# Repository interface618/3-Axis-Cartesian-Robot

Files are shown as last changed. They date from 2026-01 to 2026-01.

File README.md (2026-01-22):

<p align='center'>


<div align="center">
<h2>[2024] 3축 직교 좌표 로봇을 활용한 자동 분리수거 장치 ♻️</h2>
AI 기반 스마트 분리수거 시스템은 웹캠과 딥러닝 모델로 폐기물을 인식한 후 3축 직교좌표 로봇이 자동으로 분류까지 수행하는 시스템입니다.<br> 분류 이후에는 초음파 세척으로 이물질을 제거해 재활용품 품질까지 함께 관리합니다.<br>
</div>

## 목차
  - [개요](#개요) 
  - [작품 설명](#작품-설명)
  - [작품 작동 방식](#작품-작동-방식)
  - [역할 및 내용](#역할-및-내용)
  - [트러블 슈팅](#트러블-슈팅)
  - [코멘트](#코멘트)
## 개요
- 프로젝트 이름: ♻️ 3축 직교 좌표 로봇을 활용한 자동 분리수거 장치 ♻️
- 프로젝트 기간: 2024.07-2024.11
- 개발 엔진 및 언어: C & Python
- 멤버: Interface (이윤승 ,문영민 ,박승규 ,최성원)

## 작품 설명

현대 사회에서 재활용률 저하, 잘못된 분리수거, 이물질·라벨로 인한 재활용 품질 저하 문제를 해결하기 위해, AI 인식 + 자동 분류 + 초음파 세척 + IoT 모니터링을 하나의 운영 흐름으로 통합한 스마트 분리수거 시스템입니다.<br>
사용자가 쓰레기를 투입하면, 시스템이 객체를 인식하고 분류한 뒤 세척까지 수행하여 재활용 가능 상태로 만드는 것을 목표로 합니다.

## 작품 작동 방식

https://github.com/user-attachments/assets/98984104-4c1d-4c73-a88f-227e68fc7fe7

https://github.com/user-attachments/assets/f7063f24-820b-4ae6-a235-6e6485c27786

<h2>역할 및 내용</h2>

<table align="center">
  <thead>
    <tr>
      <th align="center">이름</th>
      <th align="center">담당 역할</th>
      <th align="center">내용</th>
    </tr>
  </thead>
  <tbody>
    <tr>
      <td nowrap align="center">이윤승</td>
      <td align="center">
        프로젝트 총괄 및<br>오수 처리 시스템 설계<br>
        초음파 세척 기능 구현, 컨베이어 벨트 제어 설계 및 3D 모델링
      </td>
      <td align="center">
        전체 요구사항/일정 관리, 모듈 간 인터페이스 정의, 오수 처리 프로세스(흐름/안전/운영 시나리오) 설계 및 통합 검증 주도<br>
        초음파 세척 모듈 구현 및 동작 조건 튜닝, 컨베이어 구동/제어 로직 설계, 기구 부품 3D 모델링 및 제작 지원
      </td>
    </tr>
    <tr>
      <td nowrap align="center">문영민</td>
      <td align="center">전원공급장치(파워서플라이)<br>설계 및 제작</td>
      <td align="center">시스템 요구 전력 분석, 전원부 구성/부품 선정, 안정적인 전원 공급을 위한 설계 반영 및 제작, 동작 테스트/검증 수행</td>
    </tr>
    <tr>
      <td nowrap align="center">박승규</td>
      <td align="center">직교좌표 로봇 제어 설계</td>
      <td align="center">3축(직교좌표) 구동 로직 설계, 홈 포지션/원점 복귀 등 안정 운용 시나리오 구성, 반복 동작 정밀도 개선을 위한 제어 파라미터 조정</td>
    </tr>
    <tr>
      <td nowrap align="center">최성원</td>
      <td align="center">영상처리 및<br>사물인식 프로그램 설계</td>
      <td align="center">카메라 기반 인식 파이프라인 설계, 인식 결과(좌표/상태) 산출 및 제어부 전달 구조 구성, 현장 디버깅을 통한 인식/전송 안정화</td>
    </tr>
  </tbody>
</table>

## 트러블 슈팅

- **3D 프린팅 출력물 규격 불일치(조립 공차 문제)**
  - 문제: 3D 모델링한 부품이 조립 시 규격이 맞지 않거나, 출력물이 예상 치수/형상과 다르게 출력되는 문제가 발생했습니다.
  - 원인: 모델 스케일/단위 설정 오류, 프린터 캘리브레이션 미흡, 슬라이서 파라미터(수축·유량·온도 등) 영향으로 치수 편차가 발생했습니다.
  - 해결: 모델 치수 재검증 후 스케일을 조정하고, 테스트 출력으로 프린터 설정(온도/속도/수축 보정)을 최적화했으며, FUSION 360에서 제공하는 조립 기능을 이용하여 시행착오를 줄였습니다.
  - 결과: 조립 공차를 만족하는 출력물을 확보하여 기구 조립을 정상적으로 진행했습니다.

- **카메라 인식 값 ↔ 직교좌표 로봇 전송(통신) 불안정**
  - 문제: 카메라에서 인식한 좌표/오프셋 값을 직교좌표 로봇 제어부로 전달하는 과정에서 값 누락/오류 등으로 정상적인 송신이 어려웠습니다.
  - 원인: 데이터 포맷 불일치, 통신 속도/버퍼 처리, 예외 상황 처리 미흡 등으로 전송 안정성이 떨어졌습니다.
  - 해결: 전송 포맷을 명확히 정의하고, 코드를 단계적으로 수정하면서 로그 기반 디버깅을 수행해 예외 처리와 버퍼 관리를 보완했습니다.
  - 결과: 인식 결과가 안정적으로 송신되며 로봇 제어에 정상 반영되었습니다.

- **파워서플라이 제작 중 손상(과전류/단락 위험)**
  - 문제: 파워서플라이 제작을 위해 제품을 분해·조립하는 과정에서 전원부가 손상되는 위기가 있었습니다.
  - 원인: 배선/결선 실수, 단락 가능성, 보호 회로 부족 등으로 전원부에 과부하가 걸릴 위험이 있었습니다.
  - 해결: 예비 전원부를 준비해 리스크를 낮추고, 결선을 하나씩 재점검하며 보호 요소(배선 정리, 절연, 연결 순서 점검 등)를 강화했습니다.
  - 결과: 시스템 요구에 맞는 안정적인 전원 공급용 파워서플라이를 구성했습니다.

- **타이밍 벨트 장력 저하로 인한 구동 불량**
  - 문제: 3축 직교좌표 로봇 구동 중 타이밍 벨트가 느슨해져 슬립이 발생하고 동작이 불안정해졌습니다.
  - 원인: 장력 부족 및 반복 구동에 따른 장력 변화로 전달 오차가 발생했습니다.
  - 해결: 벨트 장력을 재조정해 타이트하게 맞추고, 구동부 체결 상태를 재점검했습니다.
  - 결과: 축 이동이 안정화되고 반복 동작 신뢰도가 개선되었습니다.

- **장시간 구동 시 스텝 누적 오차(부동소수점 누적)**
  - 문제: 3축 직교좌표 로봇을 장시간 구동하면, 이동 스텝 값을 float(부동소수점) 기반으로 누적 계산하는 과정에서 미세 오차가 계속 쌓여 목표 위치 대비 편차가 발생했습니다.
  - 원인: 부동소수점 연산의 근사 오차가 반복적으로 누적되면서, 스텝/좌표 환산 값이 장기적으로 드리프트하는 특성이 있었습니다.
  - 해결: 누적 오차를 주기적으로 초기화하기 위해 **5분마다 홈 포지션(Home Position)으로 자동 이동**하여 기준점을 재정렬하고, 내부 좌표/스텝 누적 값을 **0으로 리셋**하는 방식으로 운용 로직을 추가했습니다.
  - 결과: 장기 구동에서도 좌표 드리프트가 억제되어 반복 작업 정밀도와 신뢰성이 개선되었습니다.

## 코멘트

- 초기 설계 단계에서 타이밍 벨트 장력 유지와 스텝 누적 오차(부동소수점 드리프트)를 충분히 고려하지 못해, 장시간 구동 후에야 슬립과 위치 편차 문제가 드러난 점이 아쉬웠습니다. 다음에는 장력 텐셔너/고정 구조를 더 견고하게 설계하고, 부동소수점 누적 오차를 줄이는 보정 로직과 주기적 홈 포지션 리셋 주기를 더 체계적으로 검증해 장기 운용 신뢰도를 근본적으로 높이고 싶습니다.

- H/W를 설계할 때 FUSION 360에 있는 시뮬레이션 툴을 사용하지 않고 실제로 출력하면서 피드백 받는 방식이 재료비 사용을 비효율적이게 운용한것 같아서 아쉬웠던 것 같다 다음에 H/W 설계할때는 시뮬레이션 툴을 사용하여 재료비 사용을 효율적으로 운용해보겠다.

- H/W 설계와 제작을 집중한 나머지 STM32의 코드 스타일을 아두이노 스타일 코딩을 해서 S/W 퀄리티가 좋지 못했던 것 같다 다음에는 역할 분배할때 H/W와 S/W 비율을 잘 조정해야할 것 같다.

- 데이터셋의 제한성이 가장 큰 문제였다. 학습에 사용한 데이터가 제한된 환경에서 수집된 이미지 중심으로 구성되어 있어, 다양한 조명 조건, 배경, 쓰레기 형태 변화에 대한 일반화 성능이 충분하지 않았다. 특히 라벨이 훼손된 플라스틱, 찌그러진 캔, 이물질이 묻은 폐기물 등 실제 분리수거 환경에서 자주 발생하는 변형된 객체에 대해 오검출 또는 미검출이 발생하는 사례가 확인되었다. 이를 통해 , 정부에서 지원해주는 AI 데이터셋을 다음에는 이용해서 더 좋은 결과를 만들고 싶다.

- 환경 요인에 따른 인식 성능 저하가 나타났다. 컨베이어 벨트 상에서 이동하는 객체는 모션 블러가 발생하고, 조명 변화 및 그림자에 따라 동일한 객체라도 인식 확률이 크게 변동하였다. 이로 인해 직교좌표 로봇의 픽앤플레이스 동작이 지연되거나 잘못된 분류 결과가 발생하는 문제가 있었다. 작업이 다 끝난 후 , OpenCV의 흑백 전환을 이용해서 물체의 형태로 구분을 했으면 더 좋은 결과가 나왔을거 같아 아쉬운 경험이였다.

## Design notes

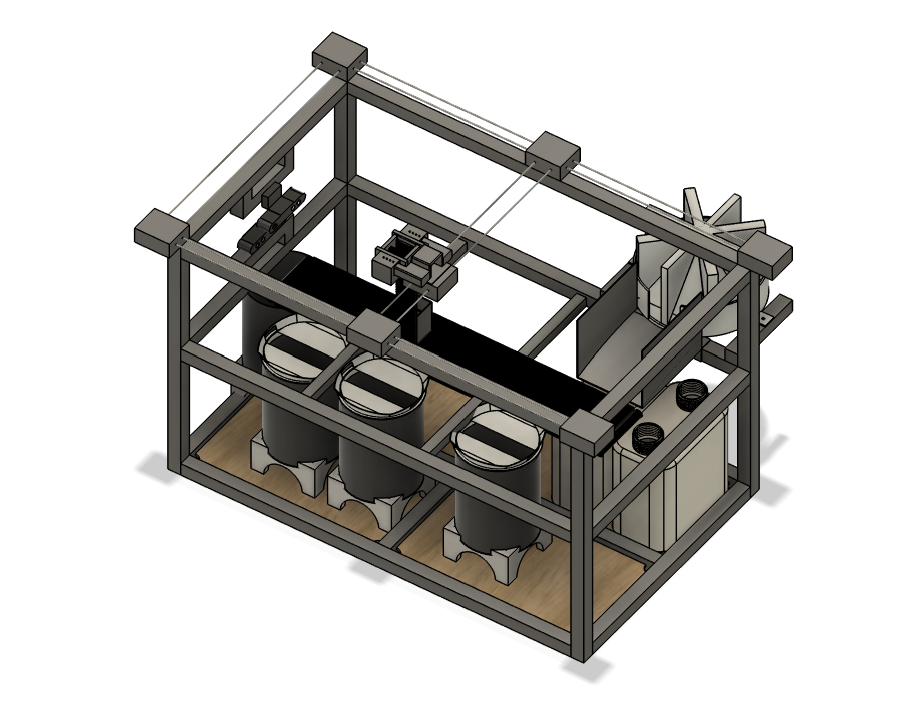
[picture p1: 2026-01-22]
3D/Total.Modeling.png

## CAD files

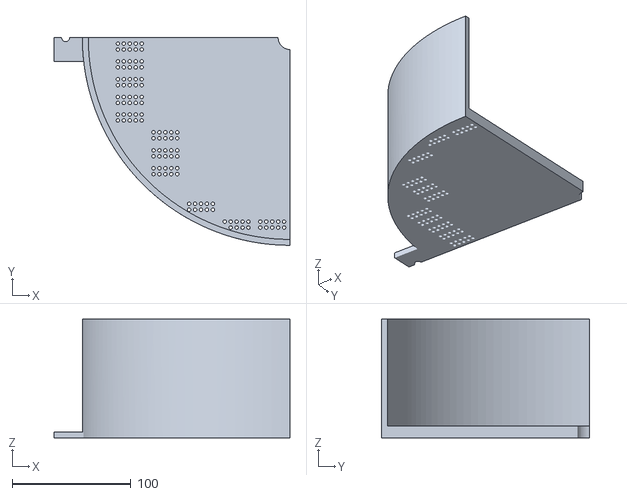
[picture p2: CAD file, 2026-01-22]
3D/분류기(외피) PART 1.stl
198.9 x 175.0 x 100.0

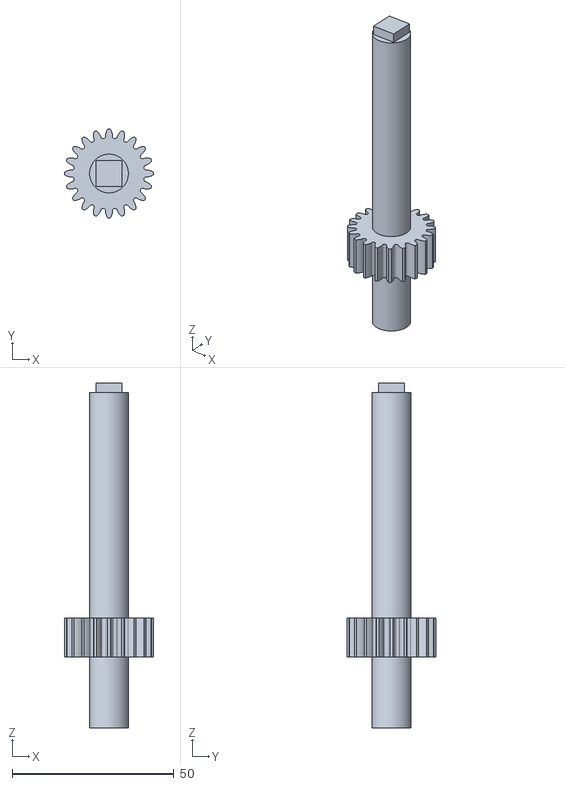
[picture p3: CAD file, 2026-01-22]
3D/분쇄기(L) 파트+Gear.stl
27.5 x 27.5 x 106.8

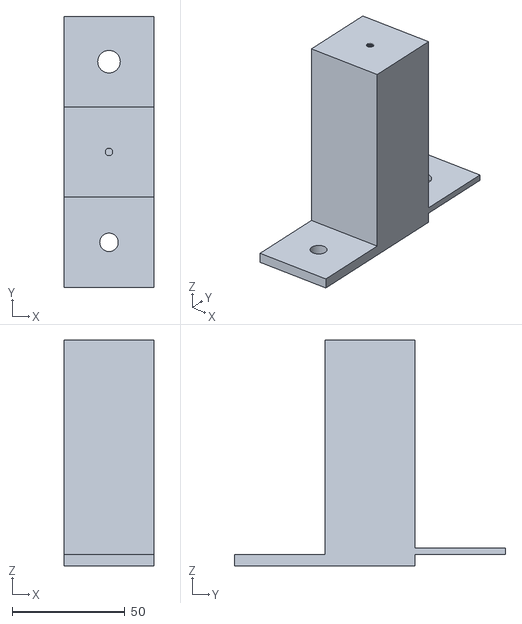
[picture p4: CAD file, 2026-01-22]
3D/쓰레기 분류기 받침대 PART 3.stl
40.0 x 120.0 x 100.0

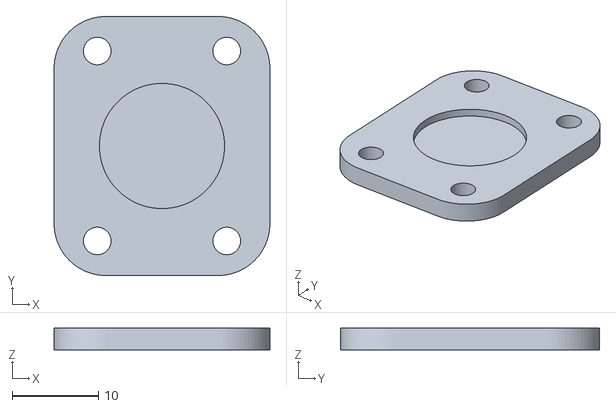
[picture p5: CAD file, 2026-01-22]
3D/압력센서 브라켓.stl
25.0 x 30.0 x 2.50

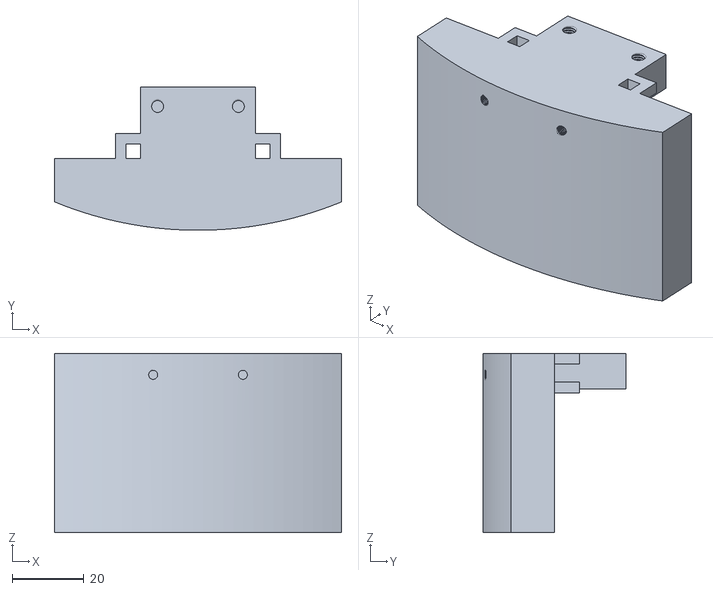
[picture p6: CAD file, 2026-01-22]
3D/초음파 수위센서 브라켓.stl
80.0 x 40.0 x 50.0

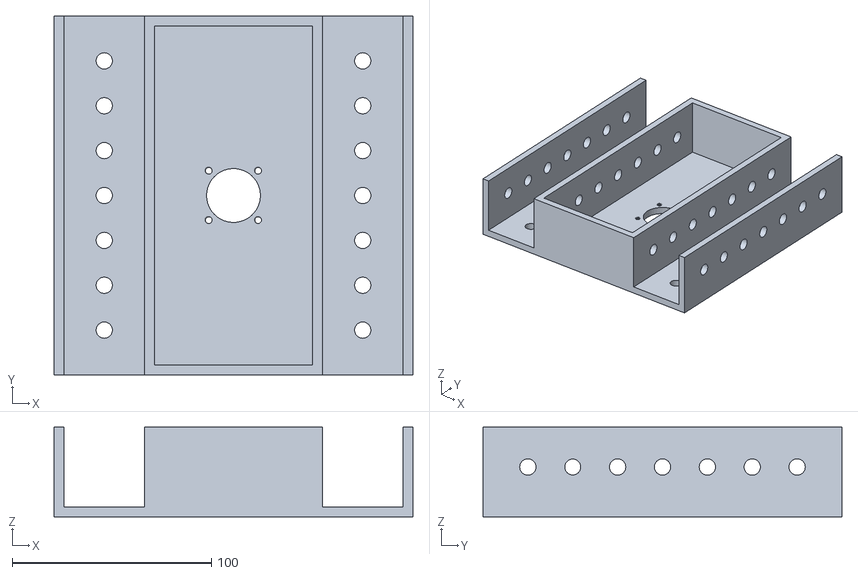
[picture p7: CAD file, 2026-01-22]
3D/K42-0084.stl
180.0 x 180.0 x 45.0

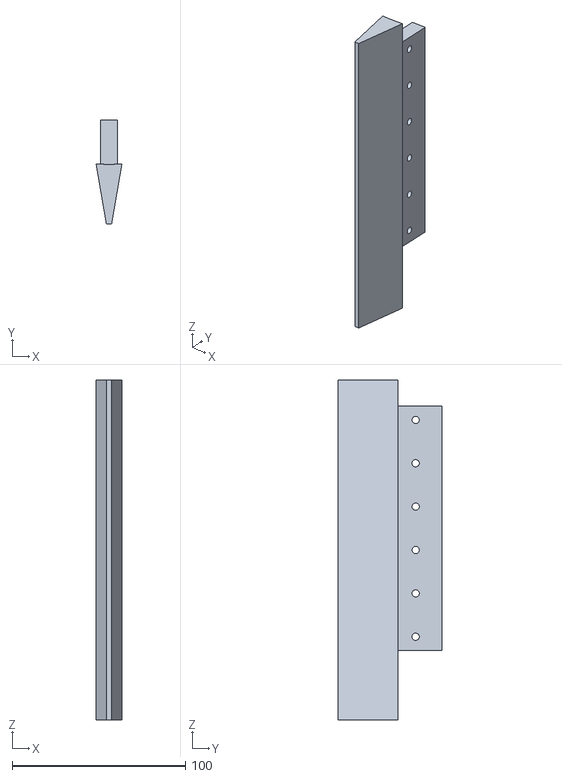
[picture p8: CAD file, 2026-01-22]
3D/쓰레기 분류기 날개(신).stl
14.9 x 60.2 x 196.0

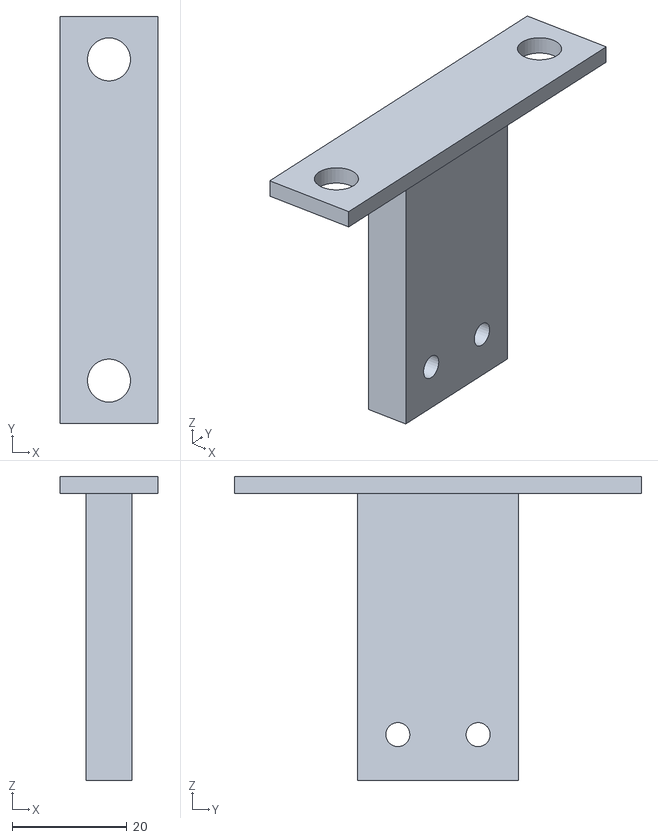
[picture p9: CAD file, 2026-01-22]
3D/베어링 브라켓(커튼 월).stl
17.0 x 71.0 x 53.0

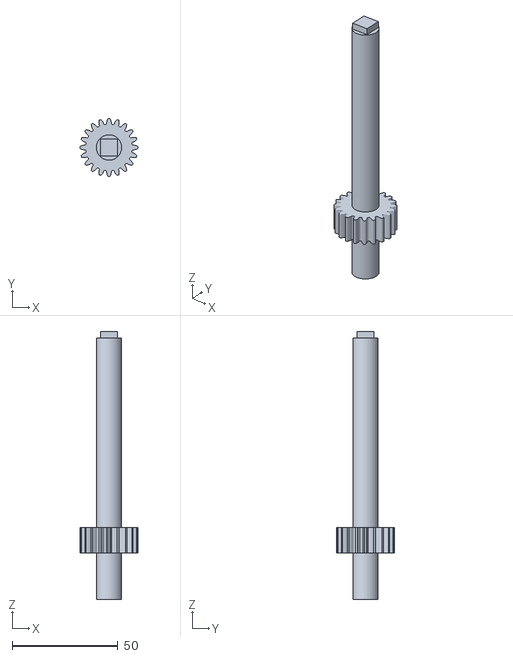
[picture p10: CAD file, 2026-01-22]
3D/분쇄기(R) 파트+Gear.stl
27.5 x 27.5 x 126.8

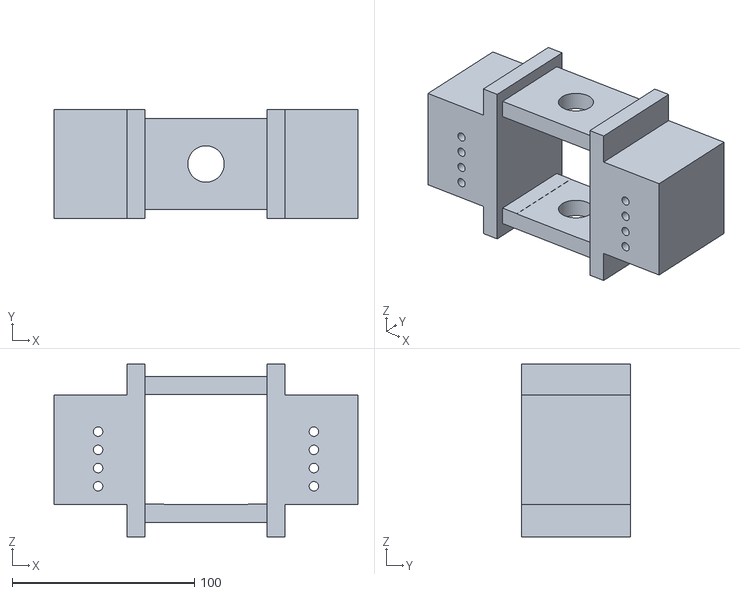
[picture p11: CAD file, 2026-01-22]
3D/M54 mk3 v8.stl
166.9 x 60.0 x 95.0

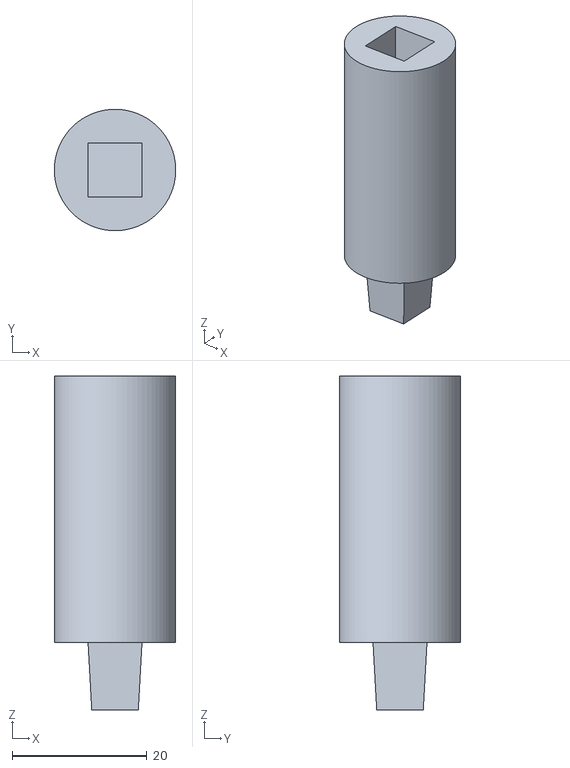
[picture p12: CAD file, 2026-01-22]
3D/분쇄기 파트 2.stl
18.0 x 18.0 x 49.5

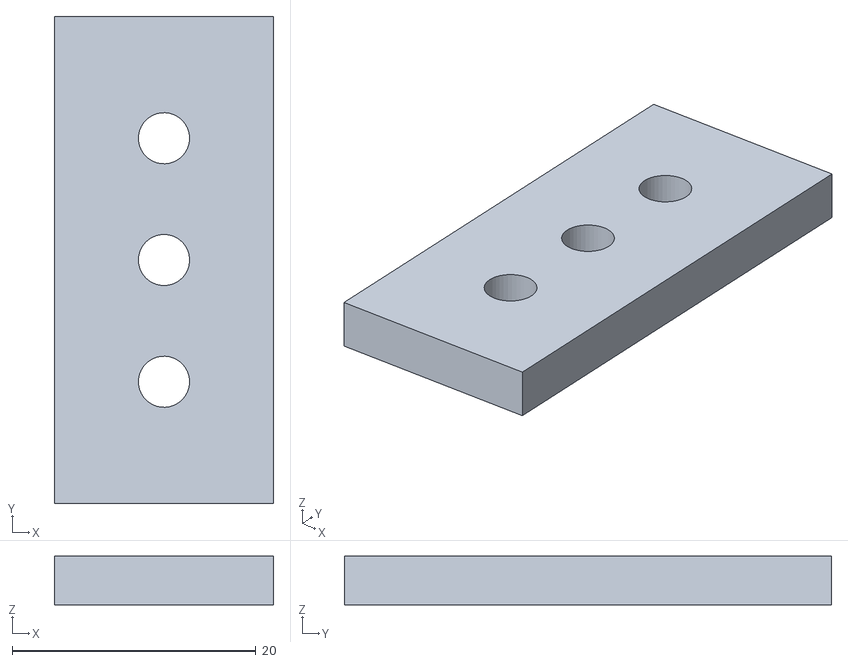
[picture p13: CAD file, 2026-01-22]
3D/부착물.stl
18.0 x 40.0 x 4.00

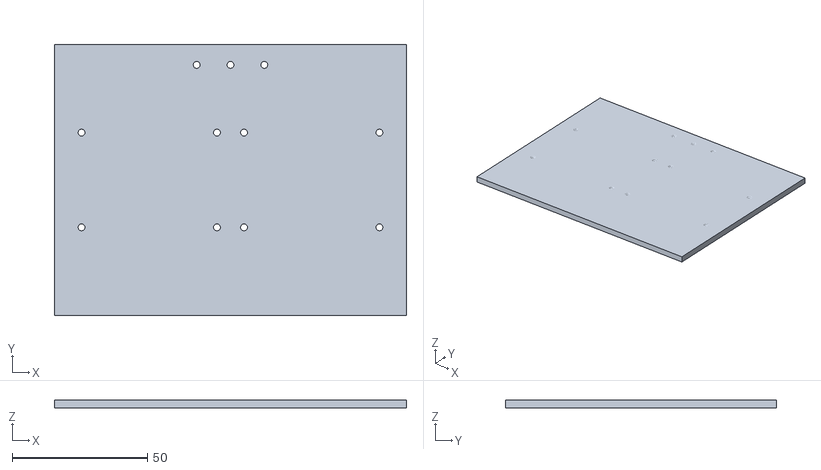
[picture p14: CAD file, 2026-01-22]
3D/워터펌프 브라켓.stl
130.0 x 100.0 x 3.00

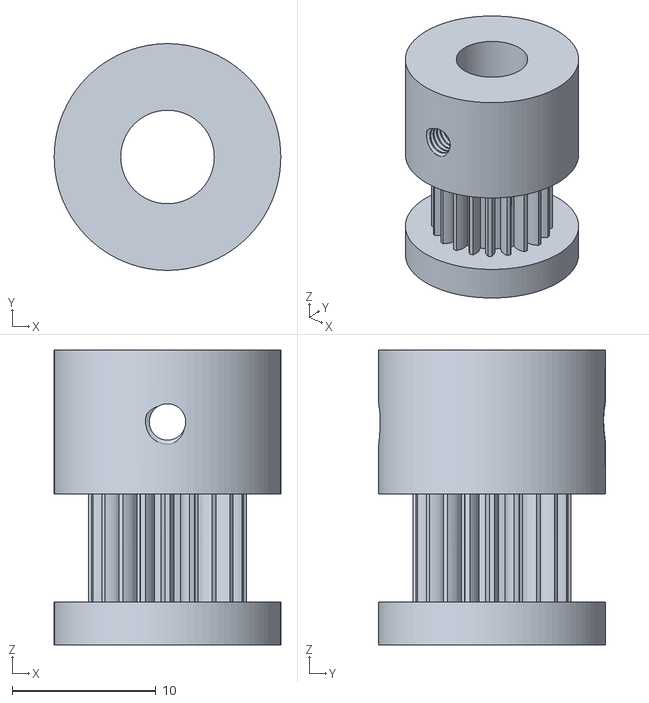
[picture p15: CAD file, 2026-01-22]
3D/GT2 풀리.stl
15.8 x 15.8 x 20.5

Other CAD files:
3D/케이블 체인 브라켓.stl
3D/쓰레기받이 상단 PART 1.stl
3D/압력센서 브라켓3 (RE) 파트 2.stl
3D/베어링 브라켓.stl
3D/Astra Pro Plus 브라켓.stl
3D/Astra Pro Plus.stl
3D/HC_SR04(BACK).stl
3D/HC_SR04(FRONT).stl
3D/M54 부속품 mk3 v3 PART 1.stl
3D/M54 부속품 mk3 v3.stl
3D/NEWTC 스텝모터 브라켓 파트 1(수정).stl
3D/c920.stl
3D/기어.stl
3D/기어봉.stl
3D/레일 version 1.stl
3D/레일 부속품 1.stl
3D/레일 부속품 3.stl
3D/레일.stl
3D/미끄럼틀 PART 1.stl
3D/미끄럼틀 PART 2.stl
3D/분류기 모터 커플러.stl
3D/분류기(내피).stl
3D/분쇄기 모터 커플러(L).stl
3D/분쇄기(L) 파트 1.stl
3D/분쇄기(R) 파트 1.stl
3D/분쇄기(R) 파트 2.stl
3D/쓰래기통 받침대.stl
3D/쓰레기 분류기 받이 Version 2 PART 4.stl
3D/압력센서 브라켓3 파트 1.stl
3D/압력센서 브라켓3.stl
3D/지지대(연장).stl
3D/컨베이어 벨트 가드(BACK).stl
3D/컨베이어 벨트 가드(SIDE).stl
3D/컨베이어 벨트 모터 샤프트.stl
3D/케이블 체인 version 4.stl
3D/케이블 체인 가드.stl
3D/케이블 체인 브라켓(BACK).stl
3D/케이블 체인 브라켓(FRONT).stl
3D/케이블 체인.stl
3D/투입구.stl
3D/풀리.stl

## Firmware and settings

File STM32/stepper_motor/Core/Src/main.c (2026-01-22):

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
/* Includes ------------------------------------------------------------------*/
#include "main.h"

/* USER CODE BEGIN Includes */
#include <stdio.h>
#include <math.h>
#include <stdlib.h>
#include <string.h>
/* USER CODE END Includes */

/* USER CODE BEGIN PD */
#ifdef __GNUC__
#define PUTCHAR_PROTOTYPE int __io_putchar(int ch)
#else
#define PUTCHAR_PROTOTYPE int fputc(int ch, FILE *f)
#endif

PUTCHAR_PROTOTYPE {
	if (ch == '\n')
		HAL_UART_Transmit(&huart2, (uint8_t*) "\r", 1, 0xFFFF);
	HAL_UART_Transmit(&huart2, (uint8_t*) &ch, 1, 0xFFFF);
	return ch;
}
/* USER CODE END PD */

TIM_HandleTypeDef htim1;
TIM_HandleTypeDef htim2;

UART_HandleTypeDef huart1;
UART_HandleTypeDef huart2;

/* USER CODE BEGIN PV */
void loop(void);
void moveStepper3(float distance_move_x, float distance_move_y);
void z_motor(void);
void move_to_bin(char bin[], int steps_needed_x, int steps_needed_y);
void moveStepper4(float distance_move_x, float distance_move_y);
int calculate_steps_to_move(float distance_mm, float pitch_mm, int pulley_teeth,
		float step_angle_deg);
void delay_us(uint32_t us);
void send_uart_message(const char *msg);
/* USER CODE END PV */

void SystemClock_Config(void);
static void MX_GPIO_Init(void);
static void MX_USART2_UART_Init(void);
static void MX_USART1_UART_Init(void);
static void MX_TIM1_Init(void);
static void MX_TIM2_Init(void);
/* USER CODE BEGIN 0 */
/* ===== UART RX (USART1) ===== */
#define RX_BUFFER_SIZE 64

volatile uint8_t rx_data = 0;
volatile char rx_buffer[RX_BUFFER_SIZE];
volatile uint16_t rx_index = 0;

volatile uint8_t data_received = 0;
volatile uint8_t received_first_value = 0;   // 0: x, 1: y, 2: object_type

volatile float distance_to_move  = 0.0f;
volatile float distance_to_move2 = 0.0f;

volatile uint8_t coordinates_received   = 0;
volatile uint8_t object_type_received   = 0;

char object_type[16] = {0};
char last_object[16] = {0};

/* ===== State flags ===== */
volatile uint8_t flag1 = 1;
volatile uint8_t flag2 = 0;
volatile uint8_t flag3 = 0;

/* ===== Step 계산/보관 ===== */
volatile int steps_needed_x2 = 0;
volatile int steps_needed_y2 = 0;

/* ===== Home / Limit switch 상태 =====
 * 1: 아직 스위치 안눌림(이동 계속), 0: 스위치 눌림(정지/완료)
 */
volatile uint8_t x_right_switch = 1;
volatile uint8_t y_switch       = 1;
volatile uint8_t z_switch       = 1;
volatile uint8_t z_rail_switch  = 1;

/* ===== Timer watchdog ===== */
volatile uint32_t timer_count = 0;
const uint32_t max_timer_count = 3000;   // 필요에 맞게 조정

/* ===== Bin 좌표(스텝 기준) / 현재 위치 =====
 * 아래 값들은 실제 장비 캘리브레이션 값으로 바꿔주세요.
 */
int can_bin_x   = 0;
int can_bin_y   = 0;
int pet_bin_x   = 0;
int pet_bin_y   = 0;
int glass_bin_x = 0;
int glass_bin_y = 0;

int current_x = 0;
int current_y = 0;

/* USER CODE END 0 */

/**
  * @brief  The application entry point.
  * @retval int
  */
int main(void)
{

  /* MCU Configuration--------------------------------------------------------*/

  /* Reset of all peripherals, Initializes the Flash interface and the Systick. */
  HAL_Init();

  /* Configure the system clock */
  SystemClock_Config();

  /* Initialize all configured peripherals */
  MX_GPIO_Init();
  MX_USART2_UART_Init();
  MX_USART1_UART_Init();
  MX_TIM1_Init();
  MX_TIM2_Init();
  /* USER CODE BEGIN 2 */
  HAL_UART_Receive_IT(&huart2, (uint8_t*)&rx_data, 1);
   HAL_TIM_Base_Start_IT(&htim1);
  /* USER CODE END 2 */

  /* Infinite loop */
  /* USER CODE BEGIN WHILE */
  while (1)
  {
	  loop();
    /* USER CODE END WHILE */

    /* USER CODE BEGIN 3 */
  }
  /* USER CODE END 3 */
}

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
/* USER CODE BEGIN 4 */
void loop(void) {
	HAL_GPIO_WritePin(GPIOB, GPIO_PIN_8, GPIO_PIN_RESET);
	HAL_GPIO_WritePin(GPIOB, GPIO_PIN_9, GPIO_PIN_RESET);
	HAL_GPIO_WritePin(GPIOC, GPIO_PIN_9, GPIO_PIN_RESET);
	HAL_GPIO_WritePin(GPIOB, GPIO_PIN_4, GPIO_PIN_RESET);
	HAL_GPIO_WritePin(GPIOC, GPIO_PIN_10, GPIO_PIN_RESET);
	HAL_GPIO_WritePin(GPIOC, GPIO_PIN_12, GPIO_PIN_RESET);
	HAL_GPIO_WritePin(GPIOB, GPIO_PIN_2, GPIO_PIN_RESET);
	if (flag1) {
		if (data_received) {
			moveStepper3(distance_to_move, distance_to_move2);
			flag1 = 0;
			flag2 = 1;
			x_right_switch = y_switch = z_switch = z_rail_switch = 1;
			timer_count = 0;
			HAL_TIM_Base_Start_IT(&htim1);
		}
	}
	if (flag2) {
		if (object_type_received) {
			if (strcmp(object_type, "can") == 0
					|| strcmp(object_type, "pet") == 0
					|| strcmp(object_type, "glass") == 0) {
				move_to_bin(object_type, steps_needed_x2, steps_needed_y2);
				if (strcmp(last_object, object_type) != 0) {
					strcpy(last_object, object_type);
				}
				x_right_switch = y_switch = z_switch = z_rail_switch = 1;
				flag2 = 0;
				flag3 = 1;
				object_type_received = 0;
				timer_count = 0;
				HAL_TIM_Base_Start_IT(&htim1);
			}
		}
	}
	if (flag3) {
		if (coordinates_received) {
			moveStepper4(distance_to_move, distance_to_move2);
			coordinates_received = 0;
			x_right_switch = y_switch = z_switch = z_rail_switch = 1;
			flag3 = 0;
			flag2 = 1;
			timer_count = 0;
			HAL_TIM_Base_Start_IT(&htim1);
		}
	}
}

void moveStepper3(float distance_move_x, float distance_move_y) {

	int steps_needed_x = calculate_steps_to_move(fabs(distance_move_x), 2.0, 20,
			0.45);
	int steps_needed_y = calculate_steps_to_move(fabs(distance_move_y), 2.0, 20,
			0.45);

	steps_needed_x2 = steps_needed_x - 3600 - 3500;
	steps_needed_y2 = 7300 - 2000 - steps_needed_y;


	if (distance_move_x < 0.0) {
		HAL_GPIO_WritePin(GPIOB, GPIO_PIN_6, GPIO_PIN_RESET);
		HAL_GPIO_WritePin(GPIOC, GPIO_PIN_7, GPIO_PIN_SET);
		HAL_GPIO_WritePin(GPIOA, GPIO_PIN_12, GPIO_PIN_RESET);
		HAL_GPIO_WritePin(GPIOA, GPIO_PIN_11, GPIO_PIN_SET);
	} else {
		HAL_GPIO_WritePin(GPIOB, GPIO_PIN_6, GPIO_PIN_SET);
		HAL_GPIO_WritePin(GPIOC, GPIO_PIN_7, GPIO_PIN_RESET);
		HAL_GPIO_WritePin(GPIOA, GPIO_PIN_12, GPIO_PIN_SET);
		HAL_GPIO_WritePin(GPIOA, GPIO_PIN_11, GPIO_PIN_RESET);
	}


	if (distance_move_y < 0.0) {
		HAL_GPIO_WritePin(GPIOC, GPIO_PIN_11, GPIO_PIN_RESET);
		HAL_GPIO_WritePin(GPIOD, GPIO_PIN_2, GPIO_PIN_SET);
	} else {
		HAL_GPIO_WritePin(GPIOC, GPIO_PIN_11, GPIO_PIN_SET);
		HAL_GPIO_WritePin(GPIOD, GPIO_PIN_2, GPIO_PIN_RESET);
	}

	steps_needed_x2 = fabs(steps_needed_x2);
	steps_needed_y2 = fabs(steps_needed_y2);

	int max_steps =
			(steps_needed_x2 > steps_needed_y2) ?
					steps_needed_x2 : steps_needed_y2;
	int step_x = 0;
	int step_y = 0;


	for (int i = 0; i < max_steps; i++) {

		if (step_x < steps_needed_x2
				&& (i % (max_steps / steps_needed_x2)) == 0) {
			HAL_GPIO_WritePin(GPIOA, GPIO_PIN_8, GPIO_PIN_SET);
			HAL_GPIO_WritePin(GPIOB, GPIO_PIN_10, GPIO_PIN_RESET);
			HAL_GPIO_WritePin(GPIOB, GPIO_PIN_12, GPIO_PIN_SET);
			HAL_GPIO_WritePin(GPIOB, GPIO_PIN_11, GPIO_PIN_RESET);
			delay_us(150);
			HAL_GPIO_WritePin(GPIOA, GPIO_PIN_8, GPIO_PIN_RESET);
			HAL_GPIO_WritePin(GPIOB, GPIO_PIN_10, GPIO_PIN_SET);
			HAL_GPIO_WritePin(GPIOB, GPIO_PIN_12, GPIO_PIN_RESET);
			HAL_GPIO_WritePin(GPIOB, GPIO_PIN_11, GPIO_PIN_SET);
			step_x++;
		}

		if (step_y < steps_needed_y2
				&& (i % (max_steps / steps_needed_y2)) == 0) {
			HAL_GPIO_WritePin(GPIOC, GPIO_PIN_2, GPIO_PIN_SET);
			HAL_GPIO_WritePin(GPIOC, GPIO_PIN_3, GPIO_PIN_RESET);
			delay_us(150);
			HAL_GPIO_WritePin(GPIOC, GPIO_PIN_2, GPIO_PIN_RESET);
			HAL_GPIO_WritePin(GPIOC, GPIO_PIN_3, GPIO_PIN_SET);
			step_y++;
		}

		delay_us(150);
	}

	distance_move_x = 0.0;
	distance_move_y = 0.0;

	z_motor();
}

void z_motor(void) {

	HAL_GPIO_WritePin(GPIOC, GPIO_PIN_4, GPIO_PIN_SET);

	for (int i = 0; i < 35000; i++) {

		HAL_GPIO_WritePin(GPIOB, GPIO_PIN_1, GPIO_PIN_SET);
		delay_us(500);
		HAL_GPIO_WritePin(GPIOB, GPIO_PIN_1, GPIO_PIN_RESET);
		delay_us(500);

		if (z_rail_switch == 0) {
			break;
		}
	}

	HAL_GPIO_WritePin(GPIOC, GPIO_PIN_1, GPIO_PIN_SET);
	HAL_Delay(3000);

	HAL_GPIO_WritePin(GPIOC, GPIO_PIN_4, GPIO_PIN_RESET);

	for (int i = 0; i < 6000; i++) {
		HAL_GPIO_WritePin(GPIOB, GPIO_PIN_1, GPIO_PIN_SET);
		delay_us(500);
		HAL_GPIO_WritePin(GPIOB, GPIO_PIN_1, GPIO_PIN_RESET);
		delay_us(500);
	}

	send_uart_message("yes\n");
}

void move_to_bin(char bin[], int steps_needed_x, int steps_needed_y) {

	HAL_TIM_Base_Stop_IT(&htim1);

	if (strcmp(bin, "can") == 0) {
		int can_move_x = can_bin_x - steps_needed_x;
		int can_move_y = can_bin_y - steps_needed_y;
		current_x = can_bin_x;
		current_y = can_bin_y;

		if (can_move_x < 0) {
			HAL_GPIO_WritePin(GPIOB, GPIO_PIN_6, GPIO_PIN_RESET);
			HAL_GPIO_WritePin(GPIOC, GPIO_PIN_7, GPIO_PIN_SET);
			HAL_GPIO_WritePin(GPIOA, GPIO_PIN_12, GPIO_PIN_RESET);
			HAL_GPIO_WritePin(GPIOA, GPIO_PIN_11, GPIO_PIN_SET);

		} else if (can_move_x > 0) {

			HAL_GPIO_WritePin(GPIOB, GPIO_PIN_6, GPIO_PIN_SET);
			HAL_GPIO_WritePin(GPIOC, GPIO_PIN_7, GPIO_PIN_RESET);
			HAL_GPIO_WritePin(GPIOA, GPIO_PIN_12, GPIO_PIN_SET);
			HAL_GPIO_WritePin(GPIOA, GPIO_PIN_11, GPIO_PIN_RESET);

		}

		if (can_move_y < 0) {
			HAL_GPIO_WritePin(GPIOC, GPIO_PIN_11, GPIO_PIN_RESET);
			HAL_GPIO_WritePin(GPIOD, GPIO_PIN_2, GPIO_PIN_SET);
		} else if (can_move_y > 0) {
			HAL_GPIO_WritePin(GPIOC, GPIO_PIN_11, GPIO_PIN_SET);
			HAL_GPIO_WritePin(GPIOD, GPIO_PIN_2, GPIO_PIN_RESET);
		}

		int additional_steps_x = fabs(can_move_x);
		int additional_steps_y = fabs(can_move_y);
		int additional_max_steps =
				(additional_steps_x > additional_steps_y) ?
						additional_steps_x : additional_steps_y;
		int step_x = 0;
		int step_y = 0;

		for (int i = 0; i < additional_max_steps; i++) {

			if (step_x < additional_steps_x
					&& (i % (additional_max_steps / additional_steps_x)) == 0) {
				HAL_GPIO_WritePin(GPIOA, GPIO_PIN_8, GPIO_PIN_SET);
				HAL_GPIO_WritePin(GPIOB, GPIO_PIN_10, GPIO_PIN_RESET);
				HAL_GPIO_WritePin(GPIOB, GPIO_PIN_12, GPIO_PIN_SET);
				HAL_GPIO_WritePin(GPIOB, GPIO_PIN_11, GPIO_PIN_RESET);
				delay_us(150);
				HAL_GPIO_WritePin(GPIOA, GPIO_PIN_8, GPIO_PIN_RESET);
				HAL_GPIO_WritePin(GPIOB, GPIO_PIN_10, GPIO_PIN_SET);
				HAL_GPIO_WritePin(GPIOB, GPIO_PIN_12, GPIO_PIN_RESET);
				HAL_GPIO_WritePin(GPIOB, GPIO_PIN_11, GPIO_PIN_SET);
				step_x++;
			}

			if (step_y < additional_steps_y
					&& (i % (additional_max_steps / additional_steps_y)) == 0) {
				HAL_GPIO_WritePin(GPIOC, GPIO_PIN_2, GPIO_PIN_SET);
				HAL_GPIO_WritePin(GPIOC, GPIO_PIN_3, GPIO_PIN_RESET);
				delay_us(150);
				HAL_GPIO_WritePin(GPIOC, GPIO_PIN_2, GPIO_PIN_RESET);
				HAL_GPIO_WritePin(GPIOC, GPIO_PIN_3, GPIO_PIN_SET);
				step_y++;
			}

			delay_us(150);

		}

	}

	else if (strcmp(bin, "pet") == 0) {
		int pet_move_x = pet_bin_x - steps_needed_x;
		int pet_move_y = pet_bin_y - steps_needed_y;
		current_x = pet_bin_x;
		current_y = pet_bin_y;

		if (pet_move_x < 0) {
			HAL_GPIO_WritePin(GPIOB, GPIO_PIN_6, GPIO_PIN_RESET);
			HAL_GPIO_WritePin(GPIOC, GPIO_PIN_7, GPIO_PIN_SET);
			HAL_GPIO_WritePin(GPIOA, GPIO_PIN_12, GPIO_PIN_RESET);
			HAL_GPIO_WritePin(GPIOA, GPIO_PIN_11, GPIO_PIN_SET);

		} else if (pet_move_x > 0) {

			HAL_GPIO_WritePin(GPIOB, GPIO_PIN_6, GPIO_PIN_SET);
			HAL_GPIO_WritePin(GPIOC, GPIO_PIN_7, GPIO_PIN_RESET);
			HAL_GPIO_WritePin(GPIOA, GPIO_PIN_12, GPIO_PIN_SET);
			HAL_GPIO_WritePin(GPIOA, GPIO_PIN_11, GPIO_PIN_RESET);

		}

		if (pet_move_y < 0) {
			HAL_GPIO_WritePin(GPIOC, GPIO_PIN_11, GPIO_PIN_RESET);
			HAL_GPIO_WritePin(GPIOD, GPIO_PIN_2, GPIO_PIN_SET);
		} else if (pet_move_y > 0) {
			HAL_GPIO_WritePin(GPIOC, GPIO_PIN_11, GPIO_PIN_SET);
			HAL_GPIO_WritePin(GPIOD, GPIO_PIN_2, GPIO_PIN_RESET);
		}

		int additional_steps_x = fabs(pet_move_x);
		int additional_steps_y = fabs(pet_move_y);
		int additional_max_steps =
				(additional_steps_x > additional_steps_y) ?
						additional_steps_x : additional_steps_y;
		int step_x = 0;
		int step_y = 0;

		for (int i = 0; i < additional_max_steps; i++) {

			if (step_x < additional_steps_x
					&& (i % (additional_max_steps / additional_steps_x)) == 0) {
				HAL_GPIO_WritePin(GPIOA, GPIO_PIN_8, GPIO_PIN_SET);
				HAL_GPIO_WritePin(GPIOB, GPIO_PIN_10, GPIO_PIN_RESET);
				HAL_GPIO_WritePin(GPIOB, GPIO_PIN_12, GPIO_PIN_SET);
				HAL_GPIO_WritePin(GPIOB, GPIO_PIN_11, GPIO_PIN_RESET);
				delay_us(150);
				HAL_GPIO_WritePin(GPIOA, GPIO_PIN_8, GPIO_PIN_RESET);
				HAL_GPIO_WritePin(GPIOB, GPIO_PIN_10, GPIO_PIN_SET);
				HAL_GPIO_WritePin(GPIOB, GPIO_PIN_12, GPIO_PIN_RESET);
				HAL_GPIO_WritePin(GPIOB, GPIO_PIN_11, GPIO_PIN_SET);
				step_x++;
			}

			if (step_y < additional_steps_y
					&& (i % (additional_max_steps / additional_steps_y)) == 0) {
				HAL_GPIO_WritePin(GPIOC, GPIO_PIN_2, GPIO_PIN_SET);
				HAL_GPIO_WritePin(GPIOC, GPIO_PIN_3, GPIO_PIN_RESET);
				delay_us(150);
				HAL_GPIO_WritePin(GPIOC, GPIO_PIN_2, GPIO_PIN_RESET);
				HAL_GPIO_WritePin(GPIOC, GPIO_PIN_3, GPIO_PIN_SET);
				step_y++;
			}

			delay_us(150);

		}

	}

	else if (strcmp(bin, "glass") == 0) {
		int glass_move_x = glass_bin_x - steps_needed_x;
		int glass_move_y = glass_bin_y - steps_needed_y;
		current_x = glass_bin_x;
		current_y = glass_bin_y;

		if (glass_move_x < 0) {
			HAL_GPIO_WritePin(GPIOB, GPIO_PIN_6, GPIO_PIN_RESET);
			HAL_GPIO_WritePin(GPIOC, GPIO_PIN_7, GPIO_PIN_SET);
			HAL_GPIO_WritePin(GPIOA, GPIO_PIN_12, GPIO_PIN_RESET);
			HAL_GPIO_WritePin(GPIOA, GPIO_PIN_11, GPIO_PIN_SET);

		} else if (glass_move_x > 0) {
			HAL_GPIO_WritePin(GPIOB, GPIO_PIN_6, GPIO_PIN_SET);
			HAL_GPIO_WritePin(GPIOC, GPIO_PIN_7, GPIO_PIN_RESET);
			HAL_GPIO_WritePin(GPIOA, GPIO_PIN_12, GPIO_PIN_SET);
			HAL_GPIO_WritePin(GPIOA, GPIO_PIN_11, GPIO_PIN_RESET);

		}

		if (glass_move_y < 0) {
			HAL_GPIO_WritePin(GPIOC, GPIO_PIN_11, GPIO_PIN_RESET);
			HAL_GPIO_WritePin(GPIOD, GPIO_PIN_2, GPIO_PIN_SET);
		} else if (glass_move_y > 0) {
			HAL_GPIO_WritePin(GPIOC, GPIO_PIN_11, GPIO_PIN_SET);
			HAL_GPIO_WritePin(GPIOD, GPIO_PIN_2, GPIO_PIN_RESET);
		}

		int additional_steps_x = fabs(glass_move_x);
		int additional_steps_y = fabs(glass_move_y);
		int additional_max_steps =
				(additional_steps_x > additional_steps_y) ?
						additional_steps_x : additional_steps_y;
		int step_x = 0;
		int step_y = 0;

		for (int i = 0; i < additional_max_steps; i++) {

			if (step_x < additional_steps_x
					&& (i % (additional_max_steps / additional_steps_x)) == 0) {
				HAL_GPIO_WritePin(GPIOA, GPIO_PIN_8, GPIO_PIN_SET);
				HAL_GPIO_WritePin(GPIOB, GPIO_PIN_10, GPIO_PIN_RESET);
				HAL_GPIO_WritePin(GPIOB, GPIO_PIN_12, GPIO_PIN_SET);
				HAL_GPIO_WritePin(GPIOB, GPIO_PIN_11, GPIO_PIN_RESET);
				delay_us(150);
				HAL_GPIO_WritePin(GPIOA, GPIO_PIN_8, GPIO_PIN_RESET);
				HAL_GPIO_WritePin(GPIOB, GPIO_PIN_10, GPIO_PIN_SET);
				HAL_GPIO_WritePin(GPIOB, GPIO_PIN_12, GPIO_PIN_RESET);
				HAL_GPIO_WritePin(GPIOB, GPIO_PIN_11, GPIO_PIN_SET);
				step_x++;
			}

			if (step_y < additional_steps_y
					&& (i % (additional_max_steps / additional_steps_y)) == 0) {
				HAL_GPIO_WritePin(GPIOC, GPIO_PIN_2, GPIO_PIN_SET);
				HAL_GPIO_WritePin(GPIOC, GPIO_PIN_3, GPIO_PIN_RESET);
				delay_us(150);
				HAL_GPIO_WritePin(GPIOC, GPIO_PIN_2, GPIO_PIN_RESET);
				HAL_GPIO_WritePin(GPIOC, GPIO_PIN_3, GPIO_PIN_SET);
				step_y++;
			}

			delay_us(150);

		}

	}
	distance_to_move = 0.0;
	distance_to_move2 = 0.0;
	HAL_Delay(2000);
	HAL_GPIO_WritePin(GPIOC, GPIO_PIN_1, GPIO_PIN_RESET);
	HAL_Delay(2000);

	send_uart_message("move\n");
}

void moveStepper4(float distance_move_x, float distance_move_y) {

	HAL_TIM_Base_Stop_IT(&htim1);

	int steps_needed_x = calculate_steps_to_move(fabs(distance_move_x), 2.0, 20,
			0.45);
	int steps_needed_y = calculate_steps_to_move(fabs(distance_move_y), 2.0, 20,
			0.45);

	int steps_needed_x3 = (steps_needed_x - 3600 - 3500) - current_x;
	int steps_needed_y3 = (steps_needed_y + 5300) - current_y;

	if (steps_needed_x3 < 0) {
		HAL_GPIO_WritePin(GPIOB, GPIO_PIN_6, GPIO_PIN_RESET);
		HAL_GPIO_WritePin(GPIOC, GPIO_PIN_7, GPIO_PIN_SET);
		HAL_GPIO_WritePin(GPIOA, GPIO_PIN_12, GPIO_PIN_RESET);
		HAL_GPIO_WritePin(GPIOA, GPIO_PIN_11, GPIO_PIN_SET);

	} else {
		HAL_GPIO_WritePin(GPIOB, GPIO_PIN_6, GPIO_PIN_SET);
		HAL_GPIO_WritePin(GPIOC, GPIO_PIN_7, GPIO_PIN_RESET);
		HAL_GPIO_WritePin(GPIOA, GPIO_PIN_12, GPIO_PIN_SET);
		HAL_GPIO_WritePin(GPIOA, GPIO_PIN_11, GPIO_PIN_RESET);

	}

	if (steps_needed_y3 < 0) {
		HAL_GPIO_WritePin(GPIOC, GPIO_PIN_11, GPIO_PIN_RESET);
		HAL_GPIO_WritePin(GPIOD, GPIO_PIN_2, GPIO_PIN_SET);
	} else {
		HAL_GPIO_WritePin(GPIOC, GPIO_PIN_11, GPIO_PIN_SET);
		HAL_GPIO_WritePin(GPIOD, GPIO_PIN_2, GPIO_PIN_RESET);
	}

	steps_needed_x3 = fabs(steps_needed_x3);
	steps_needed_y3 = fabs(steps_needed_y3);

	int max_steps3 =
			(steps_needed_x3 > steps_needed_y3) ?
					steps_needed_x3 : steps_needed_y3;
	int step_x = 0;
	int step_y = 0;

	for (int i = 0; i < max_steps3; i++) {

		if (step_x < steps_needed_x3
				&& (i % (max_steps3 / steps_needed_x3)) == 0) {
			HAL_GPIO_WritePin(GPIOA, GPIO_PIN_8, GPIO_PIN_SET);
			HAL_GPIO_WritePin(GPIOB, GPIO_PIN_10, GPIO_PIN_RESET);
			HAL_GPIO_WritePin(GPIOB, GPIO_PIN_12, GPIO_PIN_SET);
			HAL_GPIO_WritePin(GPIOB, GPIO_PIN_11, GPIO_PIN_RESET);
			delay_us(150);
			HAL_GPIO_WritePin(GPIOA, GPIO_PIN_8, GPIO_PIN_RESET);
			HAL_GPIO_WritePin(GPIOB, GPIO_PIN_10, GPIO_PIN_SET);
			HAL_GPIO_WritePin(GPIOB, GPIO_PIN_12, GPIO_PIN_RESET);
			HAL_GPIO_WritePin(GPIOB, GPIO_PIN_11, GPIO_PIN_SET);
			step_x++;
		}

		if (step_y < steps_needed_y3
				&& (i % (max_steps3 / steps_needed_y3)) == 0) {
			HAL_GPIO_WritePin(GPIOC, GPIO_PIN_2, GPIO_PIN_SET);
			HAL_GPIO_WritePin(GPIOC, GPIO_PIN_3, GPIO_PIN_RESET);
			delay_us(150);
			HAL_GPIO_WritePin(GPIOC, GPIO_PIN_2, GPIO_PIN_RESET);
			HAL_GPIO_WritePin(GPIOC, GPIO_PIN_3, GPIO_PIN_SET);
			step_y++;
		}

		delay_us(150);
	}

	distance_move_x = 0.0;
	distance_move_y = 0.0;
	distance_to_move = 0.0;
	distance_to_move2 = 0.0;
	current_x = 0;
	current_y = 0;
	steps_needed_x2 = steps_needed_x - 3600 - 3500;
	steps_needed_y2 = 7300 - 2000 - steps_needed_y;

	HAL_Delay(1000);

	z_motor();
}

void HAL_TIM_PeriodElapsedCallback(TIM_HandleTypeDef *htim) {
	if (htim->Instance == TIM1) {
		timer_count++;

		if (timer_count >= max_timer_count) {

			HAL_GPIO_WritePin(GPIOB, GPIO_PIN_8, GPIO_PIN_RESET);
			HAL_GPIO_WritePin(GPIOB, GPIO_PIN_9, GPIO_PIN_RESET);
			HAL_GPIO_WritePin(GPIOC, GPIO_PIN_9, GPIO_PIN_RESET);
			HAL_GPIO_WritePin(GPIOB, GPIO_PIN_4, GPIO_PIN_RESET);
			HAL_GPIO_WritePin(GPIOC, GPIO_PIN_10, GPIO_PIN_RESET);
			HAL_GPIO_WritePin(GPIOC, GPIO_PIN_12, GPIO_PIN_RESET);
			HAL_GPIO_WritePin(GPIOB, GPIO_PIN_2, GPIO_PIN_RESET);

			int max_steps = 26000;
			HAL_GPIO_WritePin(GPIOC, GPIO_PIN_4, GPIO_PIN_RESET);

			for (int i = 0; i < max_steps; i++) {
				if (z_switch == 1) {
					HAL_GPIO_WritePin(GPIOB, GPIO_PIN_1, GPIO_PIN_SET);
					delay_us(500);
					HAL_GPIO_WritePin(GPIOB, GPIO_PIN_1, GPIO_PIN_RESET);
					delay_us(500);
				}
			}

			HAL_GPIO_WritePin(GPIOC, GPIO_PIN_11, GPIO_PIN_RESET);
			HAL_GPIO_WritePin(GPIOD, GPIO_PIN_2, GPIO_PIN_SET);

			for (int i = 0; i < max_steps; i++) {
				if (y_switch == 1) {
					HAL_GPIO_WritePin(GPIOC, GPIO_PIN_2, GPIO_PIN_SET);
					HAL_GPIO_WritePin(GPIOC, GPIO_PIN_3, GPIO_PIN_RESET);
					delay_us(150);
					HAL_GPIO_WritePin(GPIOC, GPIO_PIN_2, GPIO_PIN_RESET);
					HAL_GPIO_WritePin(GPIOC, GPIO_PIN_3, GPIO_PIN_SET);
					delay_us(150);
				}
			}

			HAL_GPIO_WritePin(GPIOB, GPIO_PIN_6, GPIO_PIN_RESET);
			HAL_GPIO_WritePin(GPIOC, GPIO_PIN_7, GPIO_PIN_SET);
			HAL_GPIO_WritePin(GPIOA, GPIO_PIN_12, GPIO_PIN_RESET);
			HAL_GPIO_WritePin(GPIOA, GPIO_PIN_11, GPIO_PIN_SET);

			for (int i = 0; i < max_steps; i++) {
				if (x_right_switch == 1) {
					HAL_GPIO_WritePin(GPIOA, GPIO_PIN_8, GPIO_PIN_SET);
					HAL_GPIO_WritePin(GPIOB, GPIO_PIN_10, GPIO_PIN_RESET);
					HAL_GPIO_WritePin(GPIOB, GPIO_PIN_12, GPIO_PIN_SET);
					HAL_GPIO_WritePin(GPIOB, GPIO_PIN_11, GPIO_PIN_RESET);
					delay_us(150);
					HAL_GPIO_WritePin(GPIOA, GPIO_PIN_8, GPIO_PIN_RESET);
					HAL_GPIO_WritePin(GPIOB, GPIO_PIN_10, GPIO_PIN_SET);
					HAL_GPIO_WritePin(GPIOB, GPIO_PIN_12, GPIO_PIN_RESET);
					HAL_GPIO_WritePin(GPIOB, GPIO_PIN_11, GPIO_PIN_SET);
					delay_us(150);
				}
			}

			if (x_right_switch == 0 && y_switch == 0 && z_switch == 0) {
				HAL_GPIO_WritePin(GPIOB, GPIO_PIN_6, GPIO_PIN_SET);
				HAL_GPIO_WritePin(GPIOC, GPIO_PIN_7, GPIO_PIN_RESET);
				HAL_GPIO_WritePin(GPIOA, GPIO_PIN_12, GPIO_PIN_SET);
				HAL_GPIO_WritePin(GPIOA, GPIO_PIN_11, GPIO_PIN_RESET);

				for (int i = 0; i < 3600; i++) {
					HAL_GPIO_WritePin(GPIOA, GPIO_PIN_8, GPIO_PIN_SET);
					HAL_GPIO_WritePin(GPIOB, GPIO_PIN_10, GPIO_PIN_RESET);
					HAL_GPIO_WritePin(GPIOB, GPIO_PIN_12, GPIO_PIN_SET);
					HAL_GPIO_WritePin(GPIOB, GPIO_PIN_11, GPIO_PIN_RESET);

					delay_us(150);
					HAL_GPIO_WritePin(GPIOA, GPIO_PIN_8, GPIO_PIN_RESET);
					HAL_GPIO_WritePin(GPIOB, GPIO_PIN_10, GPIO_PIN_SET);
					HAL_GPIO_WritePin(GPIOB, GPIO_PIN_12, GPIO_PIN_RESET);
					HAL_GPIO_WritePin(GPIOB, GPIO_PIN_11, GPIO_PIN_SET);
					delay_us(150);
				}

				HAL_GPIO_WritePin(GPIOC, GPIO_PIN_4, GPIO_PIN_SET);

				for (int i = 0; i < 7500; i++) {
					HAL_GPIO_WritePin(GPIOB, GPIO_PIN_1, GPIO_PIN_SET);
					delay_us(500);
					HAL_GPIO_WritePin(GPIOB, GPIO_PIN_1, GPIO_PIN_RESET);
					delay_us(500);
				}
			}

			timer_count = 0;
			x_right_switch = y_switch = z_switch = z_rail_switch = 1;

			send_uart_message("move\n");

			HAL_TIM_Base_Stop_IT(&htim1);
		}

	}
}

void HAL_GPIO_EXTI_Callback(uint16_t GPIO_Pin) {
	if (GPIO_Pin == GPIO_PIN_6) {
		y_switch = 0;
	} else if (GPIO_Pin == GPIO_PIN_4) {
		x_right_switch = 0;
	} else if (GPIO_Pin == GPIO_PIN_7) {
		z_switch = 0;
	} else if (GPIO_Pin == GPIO_PIN_2) {
		z_rail_switch = 0;
	}
}

int calculate_steps_to_move(float distance_mm, float pitch_mm, int pulley_teeth,
		float step_angle_deg) {

	float pulley_circumference_mm = pitch_mm * pulley_teeth;

	float step_distance_mm = (pulley_circumference_mm * step_angle_deg) / 360.0;

	int steps_needed = (int) (distance_mm / step_distance_mm);

	return steps_needed;
}
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

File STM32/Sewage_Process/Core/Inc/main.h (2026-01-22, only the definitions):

#define B1_Pin GPIO_PIN_13
#define B1_GPIO_Port GPIOC
#define B1_EXTI_IRQn EXTI15_10_IRQn
#define USART_TX_Pin GPIO_PIN_2
#define USART_TX_GPIO_Port GPIOA
#define USART_RX_Pin GPIO_PIN_3
#define USART_RX_GPIO_Port GPIOA
#define LD2_Pin GPIO_PIN_5
#define LD2_GPIO_Port GPIOA
#define Relay3_Pin GPIO_PIN_8
#define Relay3_GPIO_Port GPIOC
#define Relay4_Pin GPIO_PIN_9
#define Relay4_GPIO_Port GPIOC
#define TRIG_Pin GPIO_PIN_8
#define TRIG_GPIO_Port GPIOA
#define ECHO_Pin GPIO_PIN_9
#define ECHO_GPIO_Port GPIOA
#define TMS_Pin GPIO_PIN_13
#define TMS_GPIO_Port GPIOA
#define TCK_Pin GPIO_PIN_14
#define TCK_GPIO_Port GPIOA
#define SWO_Pin GPIO_PIN_3
#define SWO_GPIO_Port GPIOB

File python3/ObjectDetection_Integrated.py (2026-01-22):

#!/usr/bin/env python3

import sys
import argparse
import time
import cv2
import numpy as np
import jetson.inference
import jetson.utils
from pyorbbecsdk import Config, OBSensorType, Pipeline
import serial

ESC_KEY = 27
MIN_DEPTH = 20     # 20mm를 미터로 설정
MAX_DEPTH = 10000  # 10000mm를 미터로 설정


class TemporalFilter:
    def __init__(self, alpha):
        self.alpha = alpha
        self.previous_frame = None

    def process(self, frame):
        if self.previous_frame is None:
            result = frame
        else:
            result = cv2.addWeighted(frame, self.alpha, self.previous_frame, 1 - self.alpha, 0)
        self.previous_frame = result
        return result


def map_value(center_x, old_min=150, old_max=450, new_min=-9, new_max=9):
    a = (new_max - new_min) / (old_max - old_min)
    b = new_min - a * old_min
    new_x = a * center_x + b
    return new_x


# Serial ports
ser = serial.Serial(port="/dev/ttyUSB0", baudrate=9600, timeout=None)
ser1 = serial.Serial(port="/dev/ttyACM0", baudrate=9600, timeout=None)


def send_command(command):
    command_str = " ".join(map(str, command)) + "\n"
    ser1.write(command_str.encode())
    print(f"Sent command: {command_str}")


def main():
    parser = argparse.ArgumentParser(
        description="Locate objects in a live camera stream using an object detection DNN.",
        formatter_class=argparse.RawTextHelpFormatter,
        epilog=jetson.inference.detectNet.Usage() + jetson.utils.videoSource.Usage() +
               jetson.utils.videoOutput.Usage()
    )

    parser.add_argument("input", type=str, default="", nargs='?', help="URI of the input stream for depth camera")
    parser.add_argument("output", type=str, default="display://0", nargs='?', help="URI of the output stream for object detection")
    parser.add_argument("--network", type=str,
                        default="/home/hiru/pytorch-ssd/models/canbopl/ssd-mobilenet.onnx",
                        help="pre-trained model to load")
    parser.add_argument("--labels", type=str,
                        default="/home/hiru/pytorch-ssd/models/canbopl/labels.txt",
                        help="path to labels file")
    parser.add_argument("--overlay", type=str, default="labels",
                        help="detection overlay flags")
    parser.add_argument("--threshold", type=float, default=0.1,
                        help="minimum detection threshold to use")

    args = parser.parse_known_args()[0]

    # Initialize DetectNet object
    net = jetson.inference.detectNet(
        argv=[
            "--model=" + args.network,
            "--labels=" + args.labels,
            "--input-blob=input_0",
            "--output-cvg=scores",
            "--output-bbox=boxes"
        ],
        threshold=args.threshold
    )

    # Orbbec Depth Camera setup
    config = Config()
    pipeline = Pipeline()
    temporal_filter = TemporalFilter(alpha=0.5)

    try:
        profile_list = pipeline.get_stream_profile_list(OBSensorType.DEPTH_SENSOR)
        assert profile_list is not None
        depth_profile = profile_list.get_default_video_stream_profile()
        assert depth_profile is not None
        config.enable_stream(depth_profile)
    except Exception as e:
        print(e)
        return

    pipeline.start()

    input_video = jetson.utils.videoSource("/dev/video0", argv=sys.argv + ["--width=640", "--height=480"])
    output_video = jetson.utils.videoOutput(args.output, argv=sys.argv + ["--width=640", "--height=480"])

    last_object_center_y = 0
    last_object_center_x = 0
    detection_count = 0  # 탐지 횟수

    while True:
        frames = pipeline.wait_for_frames(100)
        if frames is None:
            continue

        depth_frame = frames.get_depth_frame()
        if depth_frame is None:
            continue

        width = depth_frame.get_width()
        height = depth_frame.get_height()
        scale = depth_frame.get_depth_scale()

        depth_data = np.frombuffer(depth_frame.get_data(), dtype=np.uint16)
        depth_data = depth_data.reshape((height, width)).astype(np.float32) * scale
        depth_data = np.where((depth_data > MIN_DEPTH) & (depth_data < MAX_DEPTH), depth_data, 0)

        img = input_video.Capture()
        if img is None:
            continue

        img_np = jetson.utils.cudaToNumpy(img)
        detections = net.Detect(img, overlay=args.overlay)

        if detections:
            detection_count += 1
            print(f"Detections count: {detection_count}")

            for detection in detections:
                left = int(detection.Left)
                top = int(detection.Top)
                right = int(detection.Right)
                bottom = int(detection.Bottom)

                cv2.rectangle(img_np, (left, top), (right, bottom), (0, 255, 0), 2)

                center_x = (left + right) // 2
                center_y = (top + bottom) // 2

                cv2.circle(img_np, (center_x, center_y), 5, (0, 0, 255), -1)

                last_object_center_x = center_x
                last_object_center_y = center_y
                last_object_label = net.GetClassDesc(detection.ClassID)

                # 좌표 출력
                print(f"Current Center Coordinates: ({center_x}, {center_y})")

                # 거리 측정
                if 0 <= center_x < width and 0 <= center_y < height:
                    depth_data = temporal_filter.process(depth_data)

                    center_y = int(height / 2)
                    center_x = int(width / 2)

                    center_distance = depth_data[center_y, center_x]
                    mapped_center_x = map_value(center_x)

                    print(
                        f"Object: {last_object_label}, Center: ({mapped_center_x}, {last_object_center_y}), "
                        f"Distance: {center_distance:.2f} mm"
                    )

                    # 필요한 명령어 전송
                    if detection_count >= 150:
                        send_command(['s'])
                        time.sleep(5)

                        # 'yes' 또는 'move' 명령 처리
                        while True:
                            if ser.in_waiting > 0:
                                received_data = ser.readline().decode().strip()

                                if received_data == "yes":
                                    print("Received 'yes' command.")
                                    time.sleep(3)

                                    if last_object_label == "plastic":
                                        ser.write("pet\n".encode())
                                        print("Sent label: pet")
                                    elif last_object_label in ["can", "bottle"]:
                                        ser.write(f"{last_object_label}\n".encode())
                                        print(f"Sent label: {last_object_label}")
                                    break
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

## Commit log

2026-01-22 Expand troubleshooting section in README
    Added troubleshooting section with detailed issues and resolutions related to 3D printing, camera communication, power supply, and timing belt tension.
2026-01-22 Implement object detection using live camera stream
2026-01-22 Remove 역할 및 코멘트 section from README
    Removed '역할 및 코멘트' section from README.

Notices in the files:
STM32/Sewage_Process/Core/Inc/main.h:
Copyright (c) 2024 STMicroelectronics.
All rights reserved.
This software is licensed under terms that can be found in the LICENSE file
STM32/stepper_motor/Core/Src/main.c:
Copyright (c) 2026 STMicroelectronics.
